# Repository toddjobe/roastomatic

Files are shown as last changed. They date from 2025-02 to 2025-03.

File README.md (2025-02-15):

# roastomatic

Coffee Roasting using ESP32

I had a 4$ hot air popcorn popper that I used in 2005 for roasting coffee.  My roasting was atrocious.  I waited 20 years and people across the internets got a lot a smarter about roasting coffee at home.  So, I thought if I added bit more smarts to my hot air popcorn popper, i *might* make a decent roast.

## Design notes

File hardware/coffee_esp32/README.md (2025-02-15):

# coffee_esp32 Design

The footprints and symbols are downloaded from https://www.snapeda.com/.  See LICENSE

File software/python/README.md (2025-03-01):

# Roastomatic Python Library
This python library allows inference on the outputs of the roastomatic esp32 firmware.
It's mainly used for calibration of the various sensors.

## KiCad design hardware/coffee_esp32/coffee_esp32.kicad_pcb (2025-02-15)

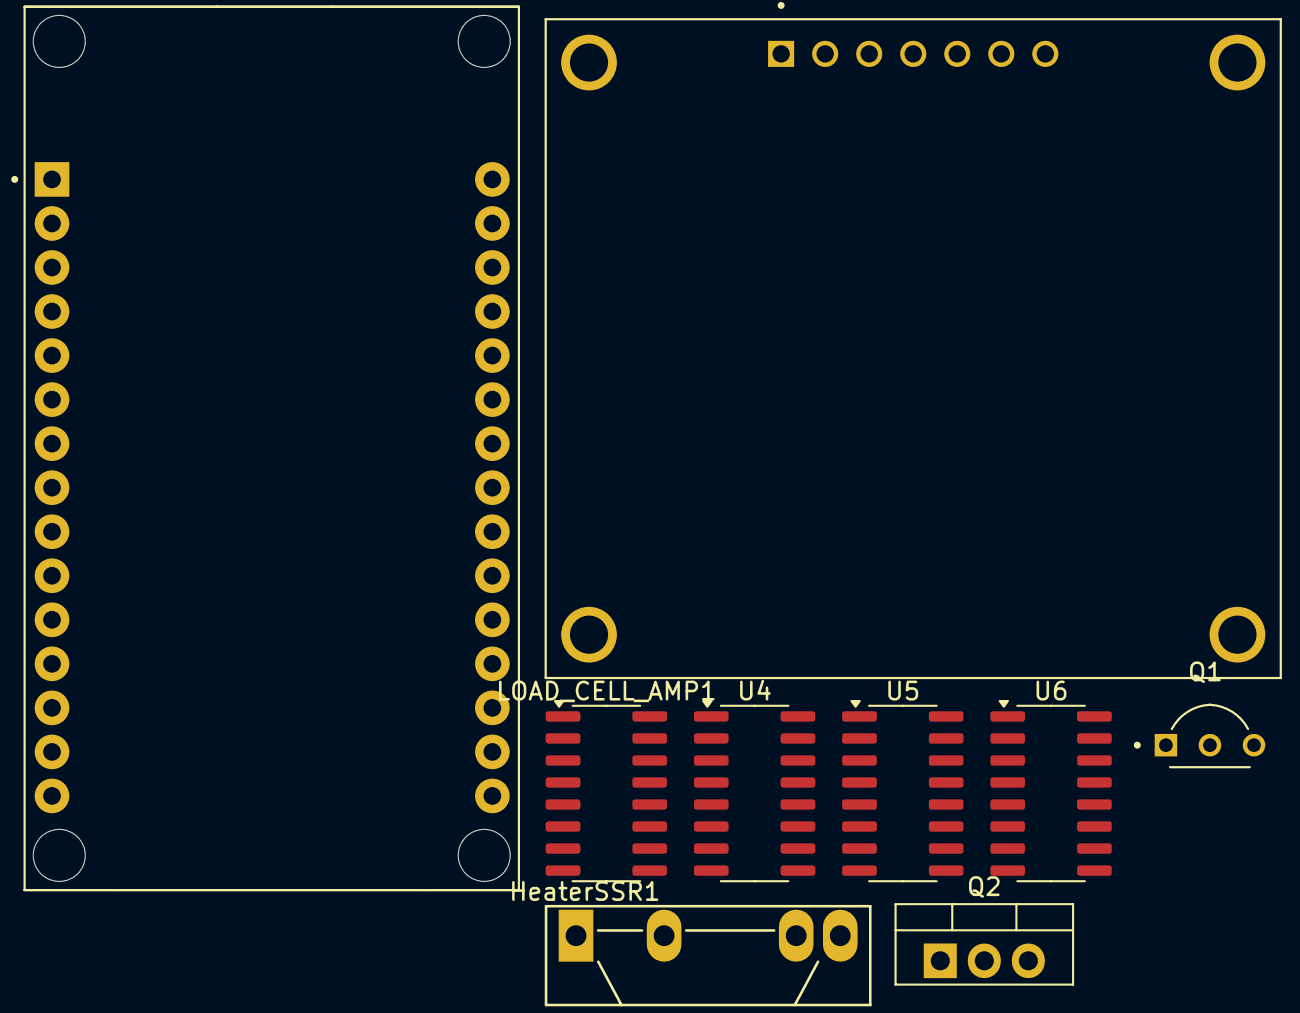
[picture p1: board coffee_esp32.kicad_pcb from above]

Board: 2 copper layers, 9 parts (0 on the bottom side), 4 nets, no tracks yet.

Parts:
DS1: AOM12864A0-1.54WW-ANO; LCD_AOM12864A0-1.54WW-ANO
HeaterSSR1: SSR-40 DA; SIP4_Sharp-SSR_P7.62mm_Straight
LOAD_CELL_AMP1: HX711; SOP-16_3.9x9.9mm_P1.27mm
Q1: 2N2222A; TO92254P470H750-3
Q2: TIP120; TO-220-3_Vertical
U1: ESP32-DEVKIT-V1; MODULE_ESP32_DEVKIT_V1
U4, U5, U6: HX711; SOP-16_3.9x9.9mm_P1.27mm

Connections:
+3.3V: DS1.2 (VDD), LOAD_CELL_AMP1.1 (VSUP), U1.1 (3V3)
/Load Cell DOUT: LOAD_CELL_AMP1.12 (DOUT), U1.19 (D34)
/Load Cell SCK: LOAD_CELL_AMP1.11 (PD_SCK), U1.20 (D35)
GND: DS1.1 (GND), HeaterSSR1.4, LOAD_CELL_AMP1.5 (AGND), Q2.3 (E), U1.2 (GND), U1.29 (GND)

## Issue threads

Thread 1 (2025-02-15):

Add KiCAD Sketches

toddjobe, 2025-02-15:
I have some KiCAD sketches that I'm working on.  I'd like to version them.

Some hints from ChatGPT:
1. **Use a `.gitignore` File** [KiCad’s official `.gitignore` template](https://github.com/github/gitignore/blob/main/KiCad.gitignore).

4. **Enable Version Control for Important Files**
   - **Version:**
     - `.kicad_pcb` (PCB layout)
     - `.kicad_sch` (Schematic)
     - `.kicad_pro` (Project settings)
     - `*.lib` (Custom symbols)
     - `*.pretty/` (Custom footprints)
   - **Ignore:**
     - `*.bak`, `*.net`, `*.log` (Temporary and auto-generated files)

### **Bonus Tips**
- If using **Git LFS**, track large files like Gerbers and 3D models (`*.step`, `*.wrl`).

Closed 2025-02-15.

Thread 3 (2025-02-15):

Setup Repository Structure

toddjobe, 2025-02-15:
name: Build and Release Hardware & Firmware

on:
  push:
    tags:
      - "v*"  # Runs only when a new tag is pushed (e.g., v1.0.0)

jobs:
  build_kicad:
    name: Generate KiCad Outputs
    runs-on: ubuntu-latest
    steps:
      - name: Checkout Repository
        uses: actions/checkout@v4

      - name: Install KiCad CLI
        run: sudo apt-get install -y kicad-cli

      - name: Generate Gerbers and BOM
        run: |
          mkdir -p hardware/output
          kicad-cli pcb export gerbers --output-dir hardware/output hardware/project1/project1.kicad_pcb
          kicad-cli sch export pdf -o hardware/output/schematic.pdf hardware/project1/project1.kicad_sch
          kicad-cli sch export netlist -o hardware/output/netlist.net hardware/project1/project1.kicad_sch

      - name: Archive KiCad Outputs
        run: |
          cd hardware/output
          zip -r kicad_release.zip *
          mv kicad_release.zip ../../

      - name: Upload KiCad Artifacts
        uses: actions/upload-artifact@v4
        with:
          name: kicad-gerbers
          path: kicad_release.zip

  build_firmware:
    name: Compile ESP32 Firmware
    runs-on: ubuntu-latest
    steps:
      - name: Checkout Repository
        uses: actions/checkout@v4

      - name: Install PlatformIO
        run: pip install platformio

      - name: Build Firmware
        run: |
          cd firmware/esp32-project1
          platformio run

      - name: Archive Firmware Binaries
        run: |
          cd firmware/esp32-project1/.pio/build/
          zip -r firmware_release.zip *
          mv firmware_release.zip ../../../../

      - name: Upload Firmware Artifacts
        uses: actions/upload-artifact@v4
        with:
          name: esp32-firmware
          path: firmware_release.zip

  release:
    name: Create GitHub Release
    needs: [build_kicad, build_firmware]
    runs-on: ubuntu-latest
    steps:
      - name: Checkout Repository
        uses: actions/checkout@v4

      - name: Download KiCad Artifacts
        uses: actions/download-artifact@v4
        with:
          name: kicad-gerbers
          path: release

      - name: Download Firmware Artifacts
        uses: actions/download-artifact@v4
        with:
          name: esp32-firmware
          path: release

      - name: Publish GitHub Release
        uses: softprops/action-gh-release@v2
        with:
          files: |
            release/kicad_release.zip
            release/firmware_release.zip
          tag_name: ${{ github.ref_name }}
          name: Release ${{ github.ref_name }}
          body: |
            🚀 **New Release** 🚀
            - **PCB Gerbers & BOM**: `kicad_release.zip`
            - **ESP32 Firmware**: `firmware_release.zip`
          draft: false
          prerelease: false

Closed 2025-02-15.

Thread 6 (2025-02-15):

Test Connected Thermocouples

toddjobe, 2025-02-15:
Just make sure we get readings from the thermocouples and they are attached to the correct pins.

Closed 2025-02-15.

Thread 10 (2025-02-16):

Test PWM of Fan

toddjobe, 2025-02-16:
I need to figure out how to test that the TIP120 is functioning correctly without running the fan.
- add terminals for all components
- see if the internal pullup resistor will work for the resistor on the transistor base.
- Just copy what you've already got in heater PWM to drive the fan.

toddjobe, 2025-02-16:
From ChatGPT:
No, the internal pull-up resistor of the ESP32 is not suitable as a base resistor for a transistor switch circuit. The reasons are:

1. **High Resistance Value** – The ESP32's internal pull-up resistor ranges from **30kΩ to 80kΩ**, which is typically too high to provide enough base current for reliable transistor switching.

2. **Unpredictable Tolerance** – The actual resistance value varies significantly, making it difficult to ensure consistent transistor operation.

3. **Limited Current Drive** – The ESP32 GPIOs have limited current output, and relying on an internal pull-up may result in insufficient base drive for the transistor.

Instead, use an external base resistor (typically **1kΩ to 10kΩ**, depending on your transistor and load) to properly control the transistor.

Closed 2025-02-19.

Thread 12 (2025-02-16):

Electrical components solve

toddjobe, 2025-02-16:
Electrical components don't have KiCad errors

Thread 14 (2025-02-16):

Design and Order PCB

toddjobe, 2025-02-16:
- Footprints are all there
- Traces work for multiple Voltages
- fits in project box
- write BOM
- order PCB and BOM

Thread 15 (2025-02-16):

Calibrate potentiometers

toddjobe, 2025-02-16:
There is input noise from the potentiometers. You could correct this at a later stage, but we can at least set a prior on the input noise.
Requirements:
- Lowest is 0
- Highest is 4095
- Spectral analysis of noise at fixed points along the resistance from low to high. Does it change across the range of resistances. (because it's bounded it likely follows a beta distribution.)
- My ability to dial the knob to a specific set point is limited, but an automated script can use all the bits. - I'm more likely to need resolution at the top end of heat. Transform the resistance to get the resolution where I need it.
- The fan dial 1 should be the minimum resistance to start the motor.

toddjobe, 2025-02-23:
The resistance applied is non-linear.  So, the dial positions don't match up.

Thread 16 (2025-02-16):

Calibrate the thermocouples

toddjobe, 2025-02-16:
We want to have a prior on thermal noise. I suspect that there's some noise introduced by the circuits
- make sure no long term (10min) bias
- spectral analysis at all temps

toddjobe, 2025-02-21:
# Load Cell Calibration Enhancements

Calibrating the load cell is the most complex aspect of this process due to multiple external factors affecting resistance measurements. Key influences include:
- **Vibration** from bean agitation.
- **Temperature fluctuations** affecting load cell resistance.
- **Potential weight shifts** due to electrical cord connections (to be evaluated later).

This issue focuses on addressing vibration and temperature effects through systematic calibration and compensation strategies.  I will make subtasks for each effect.

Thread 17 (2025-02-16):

Calibrate the load cell

toddjobe, 2025-02-16:
- need to figure out how to zero it with no weight on it
- 0 with 100 g of coffee in it.
- Run the fan without the heater with 100 g of coffee in it probably both roasted and roasted.Spectral analysis of the noise.
- Objective is to have change detection, accuracy of .01%

toddjobe, 2025-02-21:
# Load Cell Calibration Enhancements

Calibrating the load cell is the most complex aspect of this process due to multiple external factors affecting resistance measurements. Key influences include:
- **Vibration** from bean agitation.
- **Temperature fluctuations** affecting load cell resistance.
- **Potential weight shifts** due to electrical cord connections (to be evaluated later).

This issue focuses on addressing vibration and temperature effects through systematic calibration and compensation strategies.  I will create sub-issues for each.

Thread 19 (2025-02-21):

Vibration Compensation

toddjobe, 2025-02-21:
# **Problem Statement**
Bean agitation by the fan induces vibrations in the load cell, which likely vary based on bean weight. As beans dry, vibration frequency may change, potentially increasing. A low-pass filter is a straightforward way to smooth these variations.

# **Expected Outcome**
Weight readings should remain stable within **±0.1g** for a given bean weight.

# **Proposed Solution**
1. Configure a potentiometer to adjust the low-pass filter frequency.
2. Set fan to **100%**, heat to **0%**.
3. Tune the filter until a **100g weight** produces a stable reading.
4. Store the optimal frequency setting for real-time filtering.

# Next Steps
- Implement vibration filtering and validate stability at different bean weights.

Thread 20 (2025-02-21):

Vibration Compensation

toddjobe, 2025-02-21:
## Problem Statement
Bean agitation by the fan induces vibrations in the load cell, which likely vary based on bean weight. As beans dry, vibration frequency may change, potentially increasing. A low-pass filter is a straightforward way to smooth these variations.

## Expected Outcome
Weight readings should remain stable within **±0.1g** for a given bean weight.

## Proposed Solution
1. Configure a potentiometer to adjust the low-pass filter frequency.
2. Set fan to **100%**, heat to **0%**.
3. Tune the filter until a **100g weight** produces a stable reading.
4. Store the optimal frequency setting for real-time filtering.

## Next Steps
- Implement vibration filtering and validate stability at different bean weights.
- Rigorous uncertainty characterization using Gaussian Processes with temporal kernel.

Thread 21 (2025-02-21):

Temperature Compensation

toddjobe, 2025-02-21:
## Problem Statement
The load cell is mounted to the popper housing, which may conduct heat through the **metal M3 screws**. This could introduce resistance drift due to thermal expansion or material conductivity effects.

## Expected Outcome
A functional model of **resistance vs. intake temperature** that allows compensation for thermal effects.

## Proposed Solution
1. Initialize system with **fan at 100%**, heat at **0%**, and a **100.0g calibration weight**.
2. Gradually ramp heater from **0% to 100%**, logging **resistance vs. temperature**.
   - (Ramp rate should align with thermocouple calibration procedures.)
3. Apply a **low-pass filter** to detrend high-frequency fluctuations.
4. Fit a **cubic spline** to model the relationship between temperature and resistance.
5. Store the fitted values in a **lookup table** for real-time compensation.

## Next Steps
- Validate compensation model using actual roast end weights.
- Rigorous uncertainty characterization.

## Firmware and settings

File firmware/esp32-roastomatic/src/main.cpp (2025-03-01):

// MIT License
//
// Copyright (c) Todd Jobe
//
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
// Standard libraries
#include <driver/ledc.h> // PWM library.  Works with 3.0.7
#include "esp_err.h"
#include <Wire.h>
#include <stdio.h>

// Third-party libraries
#include <Adafruit_GFX.h>
#include <Adafruit_SSD1306.h>
#include <max6675.h> // Thermocouple amplifier library
#include <HX711.h>   // Load Cell amplifier Library

// Local libraries
#include "button.h"

// SSR Heater Clock setup for Pulse Width Modulation
#define HEAT_MODE LEDC_LOW_SPEED_MODE
#define HEAT_FREQUENCY 1
#define HEAT_TIMER LEDC_TIMER_0
#define HEAT_CHANNEL LEDC_CHANNEL_0
#define HEAT_DUTY_RES LEDC_TIMER_12_BIT

// TIP120 Fan Clock setup for Pulse Width Modulation
#define FAN_MODE LEDC_LOW_SPEED_MODE
#define FAN_FREQUENCY 15000
#define FAN_TIMER LEDC_TIMER_1
#define FAN_CHANNEL LEDC_CHANNEL_1
#define FAN_DUTY_RES LEDC_TIMER_12_BIT

// OLED display width and height, in pixels
const int SCREEN_WIDTH = 128;
const int SCREEN_HEIGHT = 64;
const int OLED_RESET = -1;

// I2C address for the OLED display
#define OLED_ADDRESS 0x3C

// The potentiometers will turn 270 degrees
// TODO: The resistance isn't linear.
const int ADC_BIT_DEPTH = 12;
const float MAX_DIAL = (270.0 / 360.0) * 10.0;
const int MAX_POT_VALUE = (1 << ADC_BIT_DEPTH) - 1;

// Only sample the thermocouples every 250ms
const int MIN_TEMP_SAMPLE_RATE = 250;

// Modes for HX711
struct Hx711Mode
{
  char text[22];
  void (HX711::*mode)();
};

const Hx711Mode HX711_MODES[] = {
    {"Average  ", &HX711::set_average_mode},
    {"Median   ", &HX711::set_median_mode},
    {"Med. Avg.", &HX711::set_medavg_mode},
    {"Run. Avg.", &HX711::set_runavg_mode},
    {"Raw      ", &HX711::set_raw_mode},
};

const int MIN_LOAD_CELL_SAMPLE_RATE = 100;
const float START_SCALE = 420.52;

// manual roast
const int N_WEIGHT_SAMPLES = 15;           // Number of samples to be taken for tare and calibrate scale
const float ROAST_WEIGHT_GRAMS = 90.1;     // Will be used to calibrate % drop
const float MIN_TEMP_FOR_PREHEAT = 325.0;  // Reach this temperature to trigger the TARE state.
const float MAX_BEAN_TEMP_FOR_DONE = 80.0; // dropping  below this threshold will trigger DONE state
const float MAX_HEAT_DUTY_FOR_DROP = 10;   // dropping below this threshold will trigger DROP state
const int MIN_SERIAL_PRINT_RATE = 250;     // milliseconds between serial writes
const int MIN_DISPLAY_RATE = 1000 / 60;    // 60Hz display update rate

enum MANUAL_ROAST_STATES
{
  READY,     // 0
  PREHEAT,   // 1
  TARE,      // 2
  LOAD,      // 3
  CALIBRATE, // 4
  ROAST,     // 5
  DROP,      // 6
  DONE,      // 7
  NSTATES,   // For modulo arithmetic
};

enum MANUAL_ROAST_STATES manual_roast_state;

// no more than 4 characters here
const char *state_strings[] = {
    "prep",
    "heat",
    "tare",
    "load",
    "cal.",
    "cook",
    "drop",
    "done",
    "wrap"};

// Switch between programs

typedef void (*FunctionPointer)();
struct Functions
{
  FunctionPointer setup;
  FunctionPointer loop;
};

void test_buttons_setup();
void test_display_setup();
void test_potentiometers_setup();
void test_thermocouples_setup();
void test_load_cell_setup();
void manual_roast_setup();

void test_buttons();
void test_display();
void test_potentiometers();
void test_thermocouples();
void test_load_cell();
void manual_roast();

// Selected Programs to run
const Functions FUNCTIONS[] = {
    //{test_buttons_setup, test_buttons},
    //{test_display_setup, test_display},
    //{test_potentiometers_setup, test_potentiometers},
    //{test_thermocouples_setup, test_thermocouples},
    //{test_load_cell_setup, test_load_cell},
    {manual_roast_setup, manual_roast},
};

/////////////////////////
// Pin Map
/////////////////////////

// Potentiometer pins
const int FAN_POT_PIN = 32;
const int HEAT_POT_PIN = 33;

// Thermocouple pins
// ESP32 Default SPI Pins
// MOSI 23
// MISO 19
// SCK 18
// SS 5
const int MISO_PIN = 23;
const int CS_BEAN_PIN = 5;
const int CS_INTAKE_PIN = 4;

// Screen pins
const int I2C_SDA = 21;
const int I2C_SCL = 22;

// Button pins
const int BUTTON_PINS[] = {15, 13, 12, 14, 27};
const int NUM_BUTTONS = (sizeof(BUTTON_PINS) / sizeof(*BUTTON_PINS));

// PWM pins
const int HEAT_PWM_PIN = 26;
const int FAN_PWM_PIN = 25;

// Load Cell Amplifier Pins
const int LOAD_CELL_SCK_PIN = 16;
const int LOAD_CELL_DT_PIN = 17;

/////////////
// Variables
/////////////

// Variables to hold button states and previous button states
// Button 0: Program
// Button 1: Power
// Button 2: Auto
// Button 3: Zero
// Button 4: 100g zero
Button buttons[NUM_BUTTONS] = {Button(BUTTON_PINS[0], (sizeof(FUNCTIONS) / sizeof(FUNCTIONS[0]))), Button(BUTTON_PINS[1], 3),
                               Button(BUTTON_PINS[2], 4), Button(BUTTON_PINS[3], 5),
                               Button(BUTTON_PINS[4], 6)};

// Create an instance of the SSD1306 display
Adafruit_SSD1306 display(SCREEN_WIDTH, SCREEN_HEIGHT, &Wire, OLED_RESET);

// MAX6675 Thermocouple amplifiers
MAX6675 bean_thermocouple(SCK, CS_BEAN_PIN, MISO_PIN);
MAX6675 intake_thermocouple(SCK, CS_INTAKE_PIN, MISO_PIN);

// Setup Heat PWM
ledc_timer_config_t heat_timer = {
    .speed_mode = HEAT_MODE,
    .duty_resolution = HEAT_DUTY_RES,
    .timer_num = HEAT_TIMER,
    .freq_hz = HEAT_FREQUENCY,
    .clk_cfg = LEDC_AUTO_CLK};

ledc_channel_config_t heat_channel = {
    .gpio_num = HEAT_PWM_PIN,
    .speed_mode = HEAT_MODE,
    .channel = HEAT_CHANNEL,
    .intr_type = LEDC_INTR_DISABLE,
    .timer_sel = HEAT_TIMER,
    .duty = 0,
    .hpoint = 0};

// Setup Fan PWM
ledc_timer_config_t fan_timer = {
    .speed_mode = FAN_MODE,
    .duty_resolution = FAN_DUTY_RES,
    .timer_num = FAN_TIMER,
    .freq_hz = FAN_FREQUENCY,
    .clk_cfg = LEDC_AUTO_CLK};

ledc_channel_config_t fan_channel = {
    .gpio_num = FAN_PWM_PIN,
    .speed_mode = FAN_MODE,
    .channel = FAN_CHANNEL,
    .intr_type = LEDC_INTR_DISABLE,
    .timer_sel = FAN_TIMER,
    .duty = 0,
    .hpoint = 0};

// Load Cell
HX711 scale;

// Global variables
int fan_value; // ADC value read at pin
int fan_duty;  // Duty cycle in percent
int fan_dial;  // Dial position
int heat_value;
int heat_duty;
int heat_dial;
float bean_temp_f;
float intake_temp_f;

int start_temp_sample;

// HX711 globals
float raw;
float weight;

// manual roast globals
float drop_percent = 0;
int start_roast_time = 0;
int elapsed_roast_time = 0;
int start_total_time = 0;
int elapsed_total_time = 0;
int last_display_time = 0;
int last_serial_write_time = 0;

// program globals
int current_program = 0;
char displayArray1[8][22];
char displayArray2[4][10];
void set_display_row(int row, const char *format, ...)
{
  va_list args;
  va_start(args, format);
  vsnprintf(displayArray1[row], sizeof(displayArray1[row]), format, args);
  va_end(args);
}

void displayArray()
{
  display.clearDisplay();
  display.setTextSize(1);
  display.setCursor(0, 0);

  for (int i = 0; i < sizeof(displayArray1) / sizeof(displayArray1[0]); i++)
  {
    display.println(displayArray1[i]);
  }
  display.display();
}
void setup()
{
  Serial.begin(115200);

  // Initialize the OLED display
  if (!display.begin(SSD1306_BLACK, OLED_ADDRESS))
  {
    Serial.println(F("SSD1306 allocation failed"));
    for (;;)
      ;
  }

  // Clear the display buffer
  display.clearDisplay();
  display.setTextColor(SSD1306_WHITE);
  display.setTextSize(1);

  // Initialize Buttons
  for (int i = 0; i < NUM_BUTTONS; i++)
  {
    buttons[i].begin();
  }

  // Initialize Potentiometers
  pinMode(FAN_POT_PIN, INPUT);
  pinMode(HEAT_POT_PIN, INPUT);

  // Initialize Heat PWM
  ESP_ERROR_CHECK(ledc_timer_config(&heat_timer));
  ESP_ERROR_CHECK(ledc_channel_config(&heat_channel));

  // Initialize Fan PWM
  ESP_ERROR_CHECK(ledc_timer_config(&fan_timer));
  ESP_ERROR_CHECK(ledc_channel_config(&fan_channel));

  // Initialize Load Cell
  scale.begin(LOAD_CELL_DT_PIN, LOAD_CELL_SCK_PIN, false);
  // scale.set_scale(START_SCALE);
}

void test_buttons_setup() {}
void test_buttons()
{
  display.clearDisplay();
  display.setTextSize(1);
  display.setCursor(0, 0);
  display.println("Test Buttons");

  for (int i = 0; i < NUM_BUTTONS; i++)
  {
    display.print("Button ");
    display.print(i);
    display.print(": ");
    display.println(buttons[i].count());
  }
  display.display();
}

void test_display_setup()
{
  buttons[1].setNStates(4);
}
void test_display()
{
  display.clearDisplay();
  display.setTextSize(1);
  display.setCursor(0, 0);
  display.println("Test Display");
  display.setTextSize(buttons[1].count() + 1);
  display.setCursor(0, 8);
  display.println("012345678912345678921");
  display.display();
}

void test_potentiometers_setup() {}
void test_potentiometers()
{
  char buffer[22];
  display.clearDisplay();
  display.setTextSize(1);
  display.setCursor(0, 0);
  display.println("Test Potentiometers");
  display.println("");
  display.println("Pot   Res Duty Dial");
  display.println("-------------------");
  snprintf(buffer, 22, "Fan  %4d %3d%% %1d.%02d", fan_value, fan_duty, fan_dial / 100, fan_dial % 100);
  display.println(buffer);
  snprintf(buffer, 22, "Heat %4d %3d%% %1d.%02d", heat_value, heat_duty, heat_dial / 100, heat_dial % 100);
  display.println(buffer);
  snprintf(buffer, 22, "SSR LED should match duty");
  display.println(buffer);
  display.display();
}

void test_thermocouples_setup() {}
void test_thermocouples()
{
  char float_str[7];
  int i = 0;
  set_display_row(i++, "%s", "Test Thermocouples");
  set_display_row(i++, "%s", "Therm.   F. deg.");
  set_display_row(i++, "%s", "-------------------");
  set_display_row(i++, "Intake  %s", dtostrf(intake_temp_f, 6, 2, float_str));
  set_display_row(i++, "Bean    %s", dtostrf(bean_temp_f, 6, 2, float_str));
  set_display_row(i++, "%s", "");
  set_display_row(i++, "%s", "");
  set_display_row(i++, "%s", "");
  displayArray();
}

void test_load_cell_setup()
{
  // button 1 Calls the Tare
  // button 2 Calibrates 100.0g
  // button 3 Switches between mode
  // If you weigh the whole apparatus,
  // Then get the raw value right side up
  // and with 100g.
  // Then, you get the raw value upside down.
  // and with 100g.
  // you should be able to calculate the weight of just the top part, and then store an offset
  buttons[1].setNStates(2);
  buttons[2].setNStates(2);
  buttons[3].setNStates(5);
  buttons[4].setNStates(8);
}

void test_load_cell()
{
  if (buttons[1].changed())
  {
    delay(2000);
    scale.tare();
    buttons[1].reset();
  }
  if (buttons[2].changed())
  {
    delay(2000);
    scale.calibrate_scale(100);
    buttons[2].reset();
  }
  if (buttons[3].changed())
  {
    // set hx711 mode
    int index = buttons[3].count();
    (scale.*(HX711_MODES[index].mode))();
  }

  char float_str[15];
  int i = 0;
  set_display_row(i++, "%s", "Test Scale");
  set_display_row(i++, "Mode:%d  %s", scale.get_mode(), HX711_MODES[buttons[3].count()].text);
  set_display_row(i++, "Offset:%d", (int32_t)scale.get_offset());
  set_display_row(i++, "Tare:  %d", (int32_t)scale.get_tare());
  set_display_row(i++, "Scale: %s", dtostrf(scale.get_scale(), 13, 2, float_str));
  set_display_row(i++, "Value: %d", (int32_t)scale.get_value());
  set_display_row(i++, "Gain:  %d", scale.get_gain());
  displayArray();
}
void manual_roast_setup()
{
  // button 1 Calls the Tare
  // button 2 Calibrates 100.0g
  // button 3 Switches between mode
  // If you weigh the whole apparatus,
  // Then get the raw value right side up
  // and with 100g.
  // Then, you get the raw value upside down.
  // and with 100g.
  // you should be able to calculate the weight of just the top part, and then store an offset

  buttons[1].setNStates(2);
  manual_roast_state = READY;
}

void manual_roast()
{
  // manual_roast
  // Heat and Fan are controlled by the potentiometers.
  // Steps preheat-tare-load-calibrate-roast-drop-done
  // Preheat - wait until the inside temp is higher than a french roast would be 455F
  // Tare - automatically happens with maximal sample rate.  Then switches to load.
  // Load - Look for weights above 50g.  When it detects that for at least 2 seconds
  // Calibrate @ 100g - a bunch of times, start timer, percent down
  // Roast - Timer proceeds until weight is x% and then says "drop"
  // Drop - Do nothing, you should just cut the heat manually.
  // Done -
  // Serial Write - step,millis,bean_temp,intake_temp,raw_weight.

  int t = millis();

  // increment the state with button press (as an test)
  if (buttons[1].changed())
  {
    manual_roast_state = (MANUAL_ROAST_STATES)((manual_roast_state + 1) % NSTATES);
    buttons[1].reset();
  }

  switch (manual_roast_state)
  {
  case (READY): // until a reach a temperature
    start_total_time = t;
    manual_roast_state = PREHEAT;
    break;
  case (PREHEAT): // until a reach a temperature
    if (intake_temp_f >= MIN_TEMP_FOR_PREHEAT)
    {
      manual_roast_state = TARE;
    }
    break;
  case (TARE):
    scale.tare(); // This is blocking code
    manual_roast_state = LOAD;
    break;
  case (LOAD):
    /*
    if (weight > (0.5 * ROAST_WEIGHT_GRAMS))
    {
      start_roast_time = t;
      manual_roast_state = CALIBRATE;
    }
    */
    break;
  case (CALIBRATE):
    start_roast_time = t;
    scale.calibrate_scale(ROAST_WEIGHT_GRAMS); // This is blocking code
    manual_roast_state = ROAST;
    break;
  case (ROAST):
    if (heat_duty <= MAX_HEAT_DUTY_FOR_DROP) // percent
    {
      manual_roast_state = DROP;
    }
    drop_percent = 100 * (ROAST_WEIGHT_GRAMS - weight) / ROAST_WEIGHT_GRAMS;
    elapsed_roast_time = t - start_roast_time;
    break;
  case (DROP):
    if (bean_temp_f < MAX_BEAN_TEMP_FOR_DONE)
    {
      manual_roast_state = DONE;
    }
    break;
  }

  elapsed_total_time = t - start_total_time;

  if (t - last_display_time > MIN_DISPLAY_RATE)
  {
    // bigger display than normal
    display.clearDisplay();
    display.setTextSize(2);
    display.setCursor(0, 0);

    // line 0
    char buffer[11];
    char float_string[5];
    dtostrf((drop_percent > 0.0) ? drop_percent : 0.0, 4, 2, float_string);
    snprintf(buffer, 10, "%s %s", state_strings[manual_roast_state], float_string);
    display.println(buffer);

    // line 1
    snprintf(buffer, 11, "%01ld:%02ld %02ld:%02ld",
             elapsed_roast_time / (60 * 1000), // Minutes
             (elapsed_roast_time / 1000) % 60, // Seconds
             elapsed_total_time / (60 * 1000), // Minutes
             (elapsed_total_time / 1000) % 60  // Seconds
    );
    display.println(buffer);

    // line 2
    dtostrf(bean_temp_f, 4, 1, float_string);
    snprintf(buffer, 11, "%03d %s", fan_duty, float_string);
    display.println(buffer);

    // line 3
    dtostrf(intake_temp_f, 4, 1, float_string);
    snprintf(buffer, 11, "%03d %s", heat_duty, float_string);
    display.println(buffer);
    display.display();

    last_display_time = t;
  }
  // Write a csv file to serial.
  if ((t - last_serial_write_time) > MIN_SERIAL_PRINT_RATE)
  {
    Serial.print(elapsed_roast_time);
    Serial.print(",");
    Serial.print(elapsed_total_time);
    Serial.print(",");
    Serial.print(state_strings[manual_roast_state]);
    Serial.print(",");
    Serial.print(fan_value);
    Serial.print(",");
    Serial.print(heat_value);
    Serial.print(",");
    Serial.print(bean_temp_f);
    Serial.print(",");
    Serial.print(intake_temp_f);
    Serial.print(",");
    Serial.print(weight);
    Serial.print(",");
    Serial.print(drop_percent);
    Serial.println("");
    last_serial_write_time = t;
  }
}

void loop()
{
  // Read the raw ADC potentiometer values
  fan_value = analogRead(FAN_POT_PIN);
  heat_value = analogRead(HEAT_POT_PIN);

  fan_duty = (fan_value * 100) / MAX_POT_VALUE;
  heat_duty = (heat_value * 100) / MAX_POT_VALUE;

  fan_dial = (MAX_DIAL * fan_value * 100.0) / MAX_POT_VALUE;
  heat_dial = (MAX_DIAL * heat_value * 100.0) / MAX_POT_VALUE;

  // Read the MAX6675 amplified thermocouples
  int t = millis();
  int elapsed_temp_sample = t - start_temp_sample;
  if (elapsed_temp_sample >= MIN_TEMP_SAMPLE_RATE)
  {
    bean_temp_f = bean_thermocouple.readFarenheit();
    intake_temp_f = intake_thermocouple.readFarenheit();
    start_temp_sample = t;
  }

  // Set the duty cycle of the heat PWM based on heat potentiometer
  ledc_set_duty(HEAT_MODE, HEAT_CHANNEL, heat_value);
  ledc_update_duty(HEAT_MODE, HEAT_CHANNEL);

  // Set the duty cycle of the fan PWM based on fan potentiometer
  ledc_set_duty(FAN_MODE, FAN_CHANNEL, fan_value);
  ledc_update_duty(FAN_MODE, FAN_CHANNEL);

  // Read the raw weight
  if ((t - scale.last_time_read()) >= MIN_LOAD_CELL_SAMPLE_RATE)
  {
    raw = scale.read(); // raw has least amount of blocking
    weight = scale.get_units();
  }

  // Select program
  if (current_program != buttons[0].count())
  {
    FUNCTIONS[buttons[0].count()].setup();
  }
  // Run Program
  FUNCTIONS[buttons[0].count()].loop();
}

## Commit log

2025-02-15 Created initial folder structure.
    [BOM.csv, project1.kicad_pcb, project1.kicad_sch]
2025-02-15 Added KiCad and Python gitignore templates
2025-02-15 added coffee_esp32 with hardware
    [BOM.csv, coffee_esp32.kicad_pcb, coffee_esp32.kicad_sch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]
2025-02-16 Added heater pwm
2025-02-19 PWM of fan added and tested,
2025-02-22 upgrade to kicad 9
    [coffee_esp32.kicad_sch]
2025-02-22 load cell testing tares and calibrates
    [coffee_esp32.kicad_sch]
